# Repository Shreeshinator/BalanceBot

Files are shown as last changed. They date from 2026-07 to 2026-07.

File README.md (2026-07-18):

# BalanceBot

BalanceBot is an ESP32-powered self-balancing robot project built for learning and fast iteration.  
It uses a Smartelex 9DOF board (ISM330DHCX IMU), a TB6612FNG motor driver, and a web-based tuning panel so you can adjust control settings from your phone in real time.

## Highlights

- No external IMU libraries required (direct register reads)
- PID balancing control with anti-windup safeguards
- Kalman-based angle estimation from gyro + accelerometer data
- Built-in Wi-Fi access point and browser UI for live tuning
- One-click **Capture Setpoint** for non-perfect IMU mounting
- Safety cutoff when tilt exceeds the configured safe angle

## Hardware

- ESP32 DevKit V1 (30-pin)
- Smartelex 9DOF (ISM330DHCX + MMC5983MA)
- TB6612FNG dual H-bridge motor driver
- 2 × BO geared motors + wheels
- 2-wheel chassis (included: `Chassis 1.stl`)
- Motor battery pack (typically 6–9V)
- ESP32 power source (USB power bank or regulated 5V)

> Important: motor power and ESP32 logic power should be separate, but all grounds must be shared.

## Quick Start

1. Wire the IMU and TB6612FNG to the ESP32 (see `GUIDE.md` for full pin map and diagrams).
2. Open `BalanceBot.ino` in Arduino IDE.
3. Install **ESP32 by Espressif** board support if needed.
4. Select **ESP32 Dev Module** and upload the sketch.
5. Connect to Wi-Fi: **BalanceBot** (password: **12345678**).
6. Open **http://192.168.4.1**.
7. Hold the robot at its balance point, click **Capture Setpoint**, then **Enable Robot**.
8. Tune Kp/Ki/Kd from the web UI.

## Repository Contents

- `BalanceBot.ino` — complete firmware for balancing, motor control, and web UI
- `GUIDE.md` — full beginner guide (wiring, tuning, troubleshooting)
- `Chassis 1.stl` — chassis model file

## Tuning Notes

- Start with low values and increase gradually.
- Tune **Kp** first, then **Kd**, then **Ki**.
- If motors twitch but do not move, increase `MIN_MOTOR_PWM`.
- If direction is reversed, adjust `MOTOR_LEFT_DIR` / `MOTOR_RIGHT_DIR`.

## License

No license file is currently defined in this repository. Add one if you plan to share or distribute this project publicly.

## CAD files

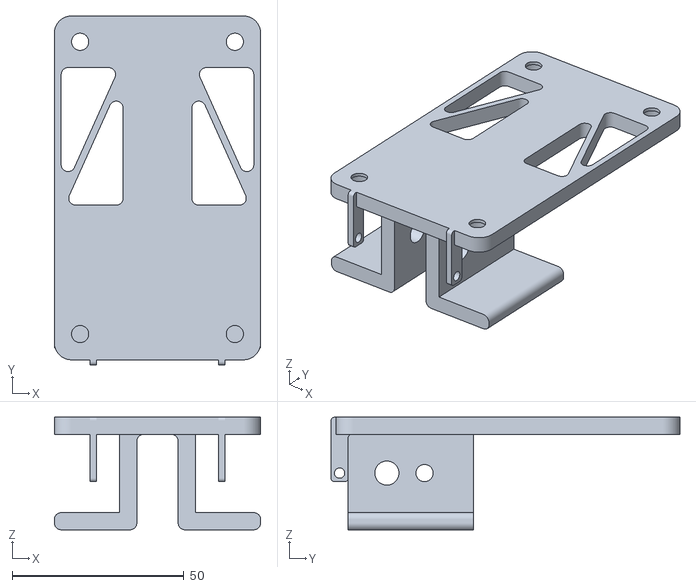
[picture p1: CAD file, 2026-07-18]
Chassis 1.stl
60.0 x 101.5 x 32.8

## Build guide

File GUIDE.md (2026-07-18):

# Self-Balancing Robot — No-Nonsense Beginner's Guide

## What You're Building

A two-wheeled robot that balances on its own like a Segway. An IMU measures how far the robot is tilting; a PID controller decides how fast to spin the motors to catch it. The ESP32 also hosts a WiFi hotspot so you can tune PID values from your phone live.

---

## Parts Checklist

| Part | Qty | Notes |
|---|---|---|
| ESP32 DevKit V1 | 1 | 30-pin variant |
| Smartelex 9DOF (ISM330DHCX + MMC5983MA) | 1 | Only the IMU chip is used for balancing |
| TB6612FNG motor driver | 1 | Dual H-bridge |
| Yellow BO gear motors | 2 | With wheels |
| Robot chassis | 1 | Two-wheeled, top-heavy = more stable |
| LiPo 7.4V or 4×AA 6V pack | 1 | Motor supply |
| USB powerbank OR 5V regulator | 1 | ESP32 supply |
| Jumper wires | many | |
| Breadboard | 1 | Optional but helpful |

**Power rule**: ESP32 and TB6612FNG logic (VCC) run on 3.3V–5V. Motors run on their own supply (VM on TB6612FNG). Always share a common GND.

---

## Wiring

### ISM330DHCX → ESP32

```
IMU Board    ESP32 DevKit V1
─────────    ───────────────
VCC      →   3V3
GND      →   GND
SDA      →   GPIO 21
SCL      →   GPIO 22
SDO/ADDR →   (leave unconnected = I2C addr 0x6A)
INT1/INT2→   (not needed)
```

### TB6612FNG → ESP32 + Battery

```
TB6612FNG   ESP32 / Power
─────────   ─────────────────────────
VCC     →   3V3            (logic power)
VM      →   Battery +      (motor power, 4–9V)
GND     →   GND            (common ground!)
STBY    →   GPIO 4         (pull HIGH to enable)
AIN1    →   GPIO 13
AIN2    →   GPIO 14
PWMA    →   GPIO 26        ← Left motor PWM
BIN1    →   GPIO 27
BIN2    →   GPIO 25
PWMB    →   GPIO 32        ← Right motor PWM
AO1/AO2 →  Left motor terminals
BO1/BO2 →  Right motor terminals
```

> ⚠️ **Critical**: Battery GND and ESP32 GND **must be connected together**. If not, the TB6612FNG direction signals won't work.

---

## About the Smartelex 9DOF Board

- **ISM330DHCX**: 3-axis accelerometer + 3-axis gyroscope by ST  
  - Accel range: ±2/4/8/16g  
  - Gyro range: ±125 to ±4000 dps  
  - I2C address: **0x6A** (default, SDO pin low)  
  - Talks I2C at up to 400 kHz — no library needed, the code reads registers directly
- **MMC5983MA**: magnetometer (compass chip) — not used for balancing  

The code uses **no external libraries** for the IMU. It talks directly to the ISM330DHCX over I2C using register addresses. This means no library to install.

---

## How the Balancing Works

```
   IMU reads tilt angle
          ↓
   Complementary filter
   (gyro + accel fusion)
          ↓
   PID controller
   (angle error → motor command)
          ↓
   TB6612FNG drives motors
   (forward if falling forward,
    backward if falling backward)
```

**Complementary filter** fuses two imperfect sensors:
- Gyroscope: accurate over short time, drifts over time
- Accelerometer: gives absolute angle, but noisy when motors vibrate

Formula: `angle = 0.98 × (angle + gyro_rate × dt) + 0.02 × accel_angle`

**PID controller**:
- **P (Proportional)**: the bigger the tilt, the harder the motor pushes — main balancing force
- **I (Integral)**: fixes a robot that always leans slightly one way
- **D (Derivative)**: slows the response down as it approaches balance — stops oscillation

---

## IMU Mounting & The Setpoint Problem

**The problem**: The IMU reads some non-zero angle when the robot is actually at its balance point, because it's mounted at an angle or not perfectly parallel to the wheel axle.

**The solution**: Don't assume setpoint = 0°. Use the web interface to set it.

### Finding the right setpoint:
1. Upload the code and open Serial Monitor (115200 baud)
2. Hold the robot at the exact point where it would balance (you can feel the "sweet spot" — lean it and find where gravity is neutral)
3. Note the angle shown on Serial Monitor
4. Open the web UI and click **"Capture Current Angle as Setpoint"**

The robot will now try to maintain **that specific angle** instead of 0°.

### Finding the right IMU axis (`PITCH_AXIS`):
In the code at the top, there's `#define PITCH_AXIS 0`. This controls which accelerometer axes are used to calculate tilt.

- Tilt the robot forward. The angle should **increase**.
- Tilt the robot backward. The angle should **decrease**.
- If it's reversed: flip `MOTOR_LEFT_DIR` and `MOTOR_RIGHT_DIR` (easier than changing axis)
- If angle doesn't change at all: try `PITCH_AXIS 1`, recompile, reupload

---

## Arduino IDE Setup

1. **Install ESP32 board support** (if not already):
   - File → Preferences → Additional Board URLs → add:  
     `https://raw.githubusercontent.com/espressif/arduino-esp32/gh-pages/package_esp32_index.json`
   - Tools → Board → Boards Manager → search "esp32" → install "esp32 by Espressif"

2. **No additional libraries needed** — the code uses only built-in ESP32 libraries (Wire, WiFi, WebServer)

3. **Board settings**:
   - Board: `ESP32 Dev Module`
   - Port: your COM/tty port
   - Upload Speed: 921600
   - Flash Frequency: 80MHz
   - Partition Scheme: Default

4. **Upload**: Press and hold the BOOT button on ESP32, click Upload, release BOOT when "Connecting..." appears (some boards do this automatically)

---

## First Run Procedure

```
Step 1: Upload code with Serial Monitor open (115200 baud)
Step 2: You'll see:
        ISM330DHCX WHO_AM_I = 0x6B ✓ OK
        Calibrating gyro — keep robot PERFECTLY STILL for 2 sec...
        Gyro offset: -0.0523 dps
        Initial angle: 12.34°
        WiFi AP "BalanceBot" started. Open: http://192.168.4.1
Step 3: Connect phone/laptop to WiFi: "BalanceBot" (password: 12345678)
Step 4: Open browser → http://192.168.4.1
Step 5: DO NOT enable yet. Hold robot upright, click "Capture Setpoint"
Step 6: Now click "Enable Robot"
Step 7: Robot will try to balance — it will fall many times while tuning PID
```

---

## PID Tuning Guide

Start with all zeros and work up:

### Step 1 — Proportional only
```
Kp = 20, Ki = 0, Kd = 0
```
The robot should react to tilting but oscillate. If it doesn't react at all, increase Kp. If it falls immediately and motors spin max, reduce Kp. Target: robot tries to correct but oscillates quickly.

### Step 2 — Add Derivative
```
Kp = 20, Ki = 0, Kd = 0.5 → increase until oscillation damps
```
Kd slows the response as it approaches vertical. Too much Kd → robot vibrates rapidly (high frequency). Good Kd → robot approaches balance and stops without wobbling.

### Step 3 — Add Integral
```
Ki = 0.2 → increase slowly
```
If the robot stays slightly tilted even when balancing, Ki fixes this. Too much Ki → slow rocking oscillation.

### Typical good starting values for BO motors + lightweight chassis:
```
Kp = 22–35
Ki = 0.3–1.0  
Kd = 0.7–2.0
```

---

## Troubleshooting

| Problem | Fix |
|---|---|
| WHO_AM_I = 0x00 or wrong | Check SDA/SCL wiring. Try I2C address 0x6B (SDO high) |
| Motors don't spin | Check STBY is GPIO 4 and HIGH. Check VM has motor power. Check GND is common |
| Motors spin wrong direction | Flip `MOTOR_LEFT_DIR` or `MOTOR_RIGHT_DIR` to -1 |
| Robot immediately falls | Setpoint is wrong — recapture it. Or Kp is too low |
| Robot oscillates rapidly | Kd too low — increase it. Or Kp too high — reduce |
| Robot slowly rocks back/forth | Ki too high — reduce. Or setpoint slightly off |
| IMU not detected | Verify 3.3V on IMU VCC pin. Try slower I2C: change `Wire.setClock(400000)` to `Wire.setClock(100000)` |
| WiFi not appearing | Normal. Reboot ESP32 and wait 5 seconds |
| Motors twitch but robot doesn't move | Increase `MIN_MOTOR_PWM` from 40 to 60 or 70 |
| LEDC compile error | You're on ESP32 Core 3.x. Replace `ledcSetup+ledcAttachPin` with `ledcAttach(pin, freq, bits)` and `ledcWrite(pin, duty)` |

---

## Getting Maximum Stability

1. **Mount the IMU rigidly** — vibration = noisy accel = bad angle estimate. Hot glue or bolt it down. Don't let it flex.

2. **Centre of mass high** — counter-intuitively, a higher CoM (battery on top) makes balancing **easier** because it falls more slowly. Low CoM = fast tipping = hard to catch.

3. **Wheels with grip** — slipping wheels mean the robot can't catch itself.

4. **Adequate motor power** — BO motors with 6V+ battery respond faster. At 3.7V they're sluggish.

5. **Keep the loop fast** — `handleClient()` is the slowest part. Typical loop rate is 150–250 Hz which is fine.

6. **Anti-windup** — already in the code. Don't remove the `pidIntegral` clamp.

7. **Increase compAlpha** — try 0.985 or 0.99 if you have motor vibration noise. Higher = more gyro trust = smoother but slightly more drift.

---

## Files

- `BalanceBot.ino` — the complete code, upload this directly in Arduino IDE

---

*No extra libraries needed. WiFi is hotspot mode (no router required). Tune from any browser.*

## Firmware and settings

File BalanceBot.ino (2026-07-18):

/*
  SELF-BALANCING ROBOT
  ESP32 DevKit V1 + Smartelex 9DOF (ISM330DHCX) + TB6612FNG
  
  Features:
    - No-library IMU (direct register access, no install needed)
    - Kalman filter (accel + gyro fusion)
    - PID controller with anti-windup
    - WiFi Access Point + live web tuner at 192.168.4.1
    - "Capture Setpoint" button for angled IMU mounting
    - Safety cutoff if robot falls too far

  TB6612FNG  →  ESP32 / Power
    VCC  →  3V3 (logic supply)
    VM   →  Battery+ (4–9V motor supply)
    GND  →  GND (shared with ESP32 and battery -)
    STBY →  GPIO 4
    AIN1 →  GPIO 13
    AIN2 →  GPIO 14
    PWMA →  GPIO 26   ← Left Motor speed
    BIN1 →  GPIO 27
    BIN2 →  GPIO 25
    PWMB →  GPIO 32   ← Right Motor speed
  ─────────────────────────────────────────────────
  NOTE: Use a common GND between ESP32 and battery.
  Power ESP32 from its VIN (5V from regulator/USB powerbank)
  or USB. Don't share motor power with ESP32 3.3V rail.
*/

#include <Wire.h>
#include <WiFi.h>
#include <WebServer.h>
#include <math.h>

//  SECTION 1: USER CONFIG — Edit these first!

// --- IMU Axis Selection ---
// With IMU mounted flat (sensor side up):
//   PITCH_AXIS = 0  → uses atan2(ax, az)  [most common]
// With IMU rotated 90° (mounted on side panel, landscape):
//   PITCH_AXIS = 1  → uses atan2(ay, az)
// With IMU tilted (another orientation):
//   PITCH_AXIS = 2  → uses atan2(ax, ay)
//
// HOW TO FIND THE RIGHT ONE:
//   Open Serial Monitor at 115200. Tilt robot forward/back.
//   The angle should increase when leaning forward and
//   decrease when leaning back. Try each until it works.
#define PITCH_AXIS   0     // 0, 1, or 2 — see above

// Matching gyro axis for pitch rate (usually same as PITCH_AXIS)
//   0 = gx,  1 = gy,  2 = gz
#define GYRO_AXIS    1     // 0, 1, or 2

// --- Motor Direction ---
// If a motor spins the wrong way, flip its sign here.
// Correct behavior: positive output → robot moves forward.
#define MOTOR_LEFT_DIR   1    //  1 or -1
#define MOTOR_RIGHT_DIR -1    //  1 or -1

// --- WiFi ---
#define WIFI_SSID  "BalanceBot"
#define WIFI_PASS  "12345678"

//  SECTION 2: PIN DEFINITIONS

// I2C (ISM330DHCX)
#define PIN_SDA   21
#define PIN_SCL   22

// TB6612FNG Motor Driver
#define PIN_STBY  4     // Standby — HIGH to enable driver

#define PIN_AIN1  13   // Motor A (Left) direction
#define PIN_AIN2  14
#define PIN_PWMA  26    // Motor A speed (PWM)

#define PIN_BIN1  27    // Motor B (Right) direction
#define PIN_BIN2  25
#define PIN_PWMB  32    // Motor B speed (PWM)

// LEDC (ESP32 hardware PWM)
#define LEDC_CHAN_A   0
#define LEDC_CHAN_B   1
#define LEDC_FREQ     10000   // 10 kHz — inaudible, smooth
#define LEDC_BITS     8       // 8-bit resolution (0–255)

//  SECTION 3: ISM330DHCX REGISTER DEFINITIONS

// I2C address (SDO pin unconnected = pulled low = 0x6A)
// If your board has SDO connected to 3.3V, use 0x6B
#define ISM330_ADDR   0x6B

#define REG_WHO_AM_I  0x0F   // Should return 0x6B
#define REG_CTRL1_XL  0x10   // Accelerometer config
#define REG_CTRL2_G   0x11   // Gyroscope config
#define REG_CTRL3_C   0x12   // General config
#define REG_OUTX_L_G  0x22   // Gyro output start (6 bytes)
#define REG_OUTX_L_A  0x28   // Accel output start (6 bytes)

// Sensitivity for our chosen full-scale ranges:
//   Gyro  ±500 dps  → 17.5 mdps/LSB
//   Accel ±2 g      → 0.061 mg/LSB
#define GYRO_SCALE    0.0175f      // dps per raw LSB
#define ACCEL_SCALE   0.000061f    // g   per raw LSB

//  SECTION 4: PID & FILTER DEFAULTS
//
// These are starting points. Tune via the web interface.
//
// Typical tuning procedure:
//   1. Set Ki=0, Kd=0. Increase Kp until robot oscillates.
//   2. Halve Kp. Increase Kd until oscillations damp.
//   3. Increase Ki slowly to remove residual lean.
//   4. Fine-tune setpoint with "Capture" button in web UI.

float Kp = 25.0f;
float Ki = 0.4f;
float Kd = 0.9f;

// Balance angle — NOT 0° if your IMU is mounted at an angle!
// Use the web interface "Capture Setpoint" button to set this
// while holding the robot at its physical balance point.
float setpoint = 0.0f;

// Safety: cut motors if robot leans more than this from setpoint
float maxSafeAngle = 70.0f;

// Complementary filter weight (0 = trust only accel, 1 = trust only gyro)
// 0.98 is the sweet spot for balance bots
float compAlpha = 0.98f;

// Minimum PWM to actually move BO motors (they stall below ~40)
#define MIN_MOTOR_PWM  50

// =========================================================
//  SECTION 5: GLOBAL STATE
// =========================================================

float currentAngle  = 0.0f;
float currentOutput = 0.0f;
float gyroOffset    = 0.0f;   // Calibrated gyro zero

float pidIntegral   = 0.0f;
float pidLastError  = 0.0f;

bool robotEnabled   = false;  // Start disabled — enable from web UI
unsigned long lastLoopUs = 0;

float loopHz = 0.0f;

float kalAngle = 0, kalBias = 0;
float kalP[2][2] = {{0,0},{0,0}};
// Tune these if needed:
const float kalQ_angle = 0.001f;  // Process noise: angle
const float kalQ_bias  = 0.003f;  // Process noise: bias drift
const float kalR_meas  = 0.03f; 

WebServer webServer(80);

// NEW --> dual core rtos split for pid and webserver
TaskHandle_t pidTaskHandle;
//protos
void imuReadAll(float&, float&, float&, float&, float&, float&);
float kalmanUpdate(float measuredAngle, float gyroRate, float dt);
void motorsOff();
void setMotors(float);
bool imuInit();
void calibrateGyro();
void setupWebServer();

void pidTask(void* pvParams) {
  lastLoopUs = micros();
  for (;;) {
    unsigned long nowUs = micros();
    float dt = (nowUs - lastLoopUs) / 1000000.0f;
    lastLoopUs = nowUs;
    dt = constrain(dt, 0.001f, 0.02f);

    float ax, ay, az, gx, gy, gz;
    imuReadAll(ax, ay, az, gx, gy, gz);

    float gyroRate;
    if      (GYRO_AXIS == 0) gyroRate = gx - gyroOffset;
    else if (GYRO_AXIS == 1) gyroRate = gy - gyroOffset;
    else                     gyroRate = gz - gyroOffset;

    float accelAngle;
    if      (PITCH_AXIS == 0) accelAngle = atan2f(ax, az) * 180.0f / M_PI;
    else if (PITCH_AXIS == 1) accelAngle = atan2f(ay, az) * 180.0f / M_PI;
    else                      accelAngle = atan2f(ax, ay) * 180.0f / M_PI;

  static float accelAngleFiltered = 0;
  accelAngleFiltered = 0.7f * accelAngleFiltered + 0.3f * accelAngle;
  // Then use accelAngleFiltered instead of accelAngle in the filter
    currentAngle = kalmanUpdate(accelAngleFiltered, gyroRate, dt);

    loopHz = 0.95f * loopHz + 0.05f * (1.0f / dt);

    float error = currentAngle - setpoint;
    if (!robotEnabled || fabsf(error) > maxSafeAngle) {
      motorsOff();
      pidIntegral = 0.0f;
      currentOutput = 0.0f;
      vTaskDelay(1);
      continue;
    }

    float Pout = Kp * error;
    pidIntegral += error * dt;
    float integralLimit = (Ki > 0.001f) ? (200.0f / Ki) : 5000.0f;
    pidIntegral = constrain(pidIntegral, -integralLimit, integralLimit);
    float Iout = Ki * pidIntegral;
    // D term: use raw gyro directly — WAY cleaner than differencing angle
    float Dout = -Kd * gyroRate;   // <-- see change #2 below

    currentOutput = Pout + Iout + Dout;
    setMotors(currentOutput);

    // Target ~500Hz — adjust this number
    vTaskDelay(pdMS_TO_TICKS(2));
  static unsigned long dbg = 0;
  if (millis() - dbg > 1000) {
    Serial.printf("enabled=%d  angle=%.2f  error=%.2f  output=%.1f\n",
      robotEnabled, currentAngle, currentAngle - setpoint, currentOutput);
    dbg = millis();
  }
  }
}

// =========================================================
//  SECTION 6: IMU FUNCTIONS
// =========================================================

void imuWrite(uint8_t reg, uint8_t val) {
  Wire.beginTransmission(ISM330_ADDR);
  Wire.write(reg);
  Wire.write(val);
  Wire.endTransmission();
}

uint8_t imuRead(uint8_t reg) {
  Wire.beginTransmission(ISM330_ADDR);
  Wire.write(reg);
  Wire.endTransmission(false);
  Wire.requestFrom(ISM330_ADDR, (uint8_t)1);
  return Wire.available() ? Wire.read() : 0;
}

// Read all 6 axes in one I2C burst (efficient, no missed frames)
void imuReadAll(float &ax, float &ay, float &az,
                float &gx, float &gy, float &gz) {
  Wire.beginTransmission(ISM330_ADDR);
  Wire.write(REG_OUTX_L_G);
  Wire.endTransmission(false);
  Wire.requestFrom(ISM330_ADDR, (uint8_t)12);

  // Gyro first (3 axes × 2 bytes), then Accel (3 axes × 2 bytes)
  int16_t rawGX = (int16_t)(Wire.read() | (Wire.read() << 8));
  int16_t rawGY = (int16_t)(Wire.read() | (Wire.read() << 8));
  int16_t rawGZ = (int16_t)(Wire.read() | (Wire.read() << 8));
  int16_t rawAX = (int16_t)(Wire.read() | (Wire.read() << 8));
  int16_t rawAY = (int16_t)(Wire.read() | (Wire.read() << 8));
  int16_t rawAZ = (int16_t)(Wire.read() | (Wire.read() << 8));

  gx = rawGX * GYRO_SCALE;
  gy = rawGY * GYRO_SCALE;
  gz = rawGZ * GYRO_SCALE;
  ax = rawAX * ACCEL_SCALE;
  ay = rawAY * ACCEL_SCALE;
  az = rawAZ * ACCEL_SCALE;
}

bool imuInit() {
  Wire.begin(PIN_SDA, PIN_SCL);
  Wire.setClock(400000);   // 400 kHz fast mode
  delay(20);

  uint8_t id = imuRead(REG_WHO_AM_I);
  Serial.printf("ISM330DHCX WHO_AM_I = 0x%02X", id);
  if (id == 0x6B) {
    Serial.println(" ✓ OK");
  } else {
    Serial.println(" ✗ FAIL — check wiring & I2C address!");
    return false;
  }

  // CTRL1_XL: ODR=208 Hz (0101xxxx), FS=±2g (xx00xxxx)
  // Byte: 0101 0000 = 0x50
  imuWrite(REG_CTRL1_XL, 0x50);

  // CTRL2_G: ODR=208 Hz (0101xxxx), FS=±500 dps (xxx0 10xx)
  // Byte: 0101 0100 = 0x54
  imuWrite(REG_CTRL2_G, 0x54);

  // CTRL3_C: BDU=1 (block data update, bit6), IF_INC=1 (auto addr inc, bit2)
  // Byte: 0100 0100 = 0x44
  imuWrite(REG_CTRL3_C, 0x44);

  delay(100);   // Let ODR settle
  return true;
}

void calibrateGyro() {
  Serial.println("Calibrating gyro — keep robot PERFECTLY STILL for 2 sec...");
  const int N = 400;
  float sum = 0;
  for (int i = 0; i < N; i++) {
    float ax, ay, az, gx, gy, gz;
    imuReadAll(ax, ay, az, gx, gy, gz);
    float g = (GYRO_AXIS == 0) ? gx : (GYRO_AXIS == 1) ? gy : gz;
    sum += g;
    delay(5);
  }
  gyroOffset = sum / N;
  Serial.printf("Gyro offset: %.4f dps\n", gyroOffset);

  // Seed angle from accelerometer so filter starts correct
  float ax, ay, az, gx, gy, gz;
  imuReadAll(ax, ay, az, gx, gy, gz);
  if      (PITCH_AXIS == 0) currentAngle = atan2f(ax, az) * 180.0f / M_PI;
  else if (PITCH_AXIS == 1) currentAngle = atan2f(ay, az) * 180.0f / M_PI;
  else                      currentAngle = atan2f(ax, ay) * 180.0f / M_PI;
  Serial.printf("Initial angle: %.2f°\n", currentAngle);
  kalAngle = currentAngle;
}

// =========================================================
//  SECTION 7: MOTOR CONTROL
// =========================================================

void motorsInit() {
  pinMode(PIN_AIN1, OUTPUT);  pinMode(PIN_AIN2, OUTPUT);
  pinMode(PIN_BIN1, OUTPUT);  pinMode(PIN_BIN2, OUTPUT);
  pinMode(PIN_STBY, OUTPUT);
  digitalWrite(PIN_STBY, HIGH);  // Enable driver

  // ESP32 Arduino Core 2.x LEDC API
  // (If you're on Core 3.x, replace with ledcAttach(pin, freq, bits))
  ledcAttach(PIN_PWMA, LEDC_FREQ, LEDC_BITS);
  ledcAttach(PIN_PWMB, LEDC_FREQ, LEDC_BITS);
}

// Drive one H-bridge channel. speed: -255 to +255
void driveChannel(uint8_t in1, uint8_t in2, uint8_t pwmPin, int speed) {
  speed = constrain(speed, -255, 255);
  if (speed > 0) {
    digitalWrite(in1, HIGH); digitalWrite(in2, LOW);
    ledcWrite(pwmPin, speed);
  } else if (speed < 0) {
    digitalWrite(in1, LOW);  digitalWrite(in2, HIGH);
    ledcWrite(pwmPin, -speed);
  } else {
    // Fast decay (coast): both inputs LOW
    digitalWrite(in1, LOW);  digitalWrite(in2, LOW);
    ledcWrite(pwmPin, 0);
  }
}

// Apply PID output to both motors.
// Positive output = both motors drive "forward" (catching a forward lean).
void setMotors(float rawOutput) {
  int out = (int)constrain(rawOutput, -255.0f, 255.0f);

  // Dead zone: too small to do anything → zero
  if (abs(out) < 12) {
    out = 0;
  }
// Stiction zone: too small to move but non-trivial → snap to minimum
  else if (abs(out) < MIN_MOTOR_PWM) {
    out = (out > 0) ? MIN_MOTOR_PWM : -MIN_MOTOR_PWM;
  }

  driveChannel(PIN_AIN1, PIN_AIN2, PIN_PWMA, MOTOR_LEFT_DIR  * out);
  driveChannel(PIN_BIN1, PIN_BIN2, PIN_PWMB, MOTOR_RIGHT_DIR * out);
}

void motorsOff() {
  driveChannel(PIN_AIN1, PIN_AIN2, PIN_PWMA, 0);
  driveChannel(PIN_BIN1, PIN_BIN2, PIN_PWMB, 0);
}

// =========================================================
//  SECTION 8: WEB INTERFACE HTML
// =========================================================

// Stored in flash (PROGMEM) to save RAM
const char INDEX_HTML[] PROGMEM = R"rawhtml(
<!DOCTYPE html><html lang="en">
<head>
<meta charset="UTF-8">
<meta name="viewport" content="width=device-width,initial-scale=1">
<title>BalanceBot Tuner</title>
<style>
*{box-sizing:border-box;margin:0;padding:0}
body{background:#0d1117;color:#c9d1d9;font-family:system-ui,sans-serif;padding:14px;max-width:480px;margin:auto}
h1{font-size:1.3em;color:#58a6ff;margin-bottom:14px}
.card{background:#161b22;border:1px solid #30363d;border-radius:10px;padding:14px;margin-bottom:12px}
.row{display:flex;gap:12px}
.cell{flex:1;text-align:center}
.big{font-size:2em;font-weight:700;line-height:1.1}
.green{color:#3fb950}.red{color:#f85149}.blue{color:#58a6ff}.yellow{color:#d29922}
.sub{font-size:.75em;color:#8b949e;margin-top:2px}
.bar-bg{height:10px;background:#21262d;border-radius:5px;overflow:hidden;margin:10px 0}
.bar{height:100%;background:#58a6ff;border-radius:5px;transition:width .08s}
label{display:block;font-size:.8em;color:#8b949e;margin:10px 0 3px}
input[type=number]{width:100%;background:#21262d;color:#c9d1d9;border:1px solid #30363d;border-radius:6px;padding:7px 10px;font-size:.95em}
input[type=number]:focus{border-color:#58a6ff;outline:none}
.btn{width:100%;border:none;border-radius:7px;padding:10px;font-size:.95em;cursor:pointer;margin-top:6px;font-weight:600}
.btn-blue{background:#1f6feb;color:#fff}
.btn-green{background:#238636;color:#fff}
.btn-red{background:#da3633;color:#fff}
.btn-gray{background:#21262d;color:#c9d1d9;border:1px solid #30363d}
.tip{font-size:.78em;color:#8b949e;line-height:1.5}
.tip b{color:#d29922}
.status{font-size:.8em;margin-top:8px}
.dot{display:inline-block;width:8px;height:8px;border-radius:50%;margin-right:5px}
</style>
</head>
<body>
<h1>⚖️ BalanceBot Tuner</h1>

<div class="card">
  <div class="row">
    <div class="cell">
      <div class="sub">Tilt Angle</div>
      <div class="big" id="ang" style="color:#58a6ff">--</div>
      <div class="sub">degrees</div>
    </div>
    <div class="cell">
      <div class="sub">Motor Drive</div>
      <div class="big" id="out" style="color:#3fb950">--</div>
      <div class="sub">/ ±255</div>
    </div>
    <div class="cell">
      <div class="sub">Loop Rate</div>
      <div class="big" id="hz" style="color:#d29922">--</div>
      <div class="sub">Hz</div>
    </div>
  </div>
  <div class="bar-bg"><div class="bar" id="angbar" style="width:50%"></div></div>
  <div class="status" id="statusline"><span class="dot" style="background:#555" id="dot"></span>Connecting...</div>
</div>

<div class="card">
  <b style="color:#c9d1d9">PID Parameters</b>
  <label>Kp — Proportional (main restoring force, 15-40 typical)</label>
  <input type="number" id="kp" step="0.5" min="0" max="200">
  <label>Ki — Integral (removes steady lean, 0-2 typical)</label>
  <input type="number" id="ki" step="0.05" min="0" max="20">
  <label>Kd — Derivative (damps oscillation, 0.5-3 typical)</label>
  <input type="number" id="kd" step="0.05" min="0" max="20">
  <label>Setpoint (°) — angle where robot balances</label>
  <input type="number" id="sp" step="0.1">
  <label>Max Safe Angle (°) — motors cut if exceeded</label>
  <input type="number" id="ma" step="1" min="5" max="90">
  <button class="btn btn-blue" onclick="applyPID()">✓ Apply Parameters</button>
  <button class="btn btn-gray" onclick="captureSetpoint()" style="margin-top:5px">
    📐 Capture Current Angle as Setpoint
  </button>
</div>

<div class="card row" style="gap:8px">
  <button class="btn btn-green" onclick="setEn(1)">▶ Enable Robot</button>
  <button class="btn btn-red" onclick="setEn(0)">■ Disable</button>
</div>

<div class="card">
  <b style="color:#d29922">Tuning Guide</b>
  <p class="tip" style="margin-top:8px">
    <b>Step 1</b> — Set Ki=0, Kd=0. Raise Kp until robot tries to balance but oscillates.<br>
    <b>Step 2</b> — Halve Kp. Raise Kd to damp oscillations.<br>
    <b>Step 3</b> — Raise Ki slowly (0.1 at a time) to fix residual lean.<br>
    <b>Step 4</b> — If motors twitch but robot doesn't move, raise MIN_MOTOR_PWM in code.<br>
    <b>Setpoint</b> — Hold robot at real balance point, click Capture. Re-enable.
  </p>
</div>

<script>
let liveAngle=0, lastTime=Date.now(), loopCnt=0;

async function poll(){
  try{
    const d=await(await fetch('/data')).json();
    liveAngle=d.angle;
    document.getElementById('ang').textContent=d.angle.toFixed(1);
    document.getElementById('out').textContent=(d.output>=0?'+':'')+Math.round(d.output);
    document.getElementById('hz').textContent=Math.round(d.hz);
    // Angle bar: ±30° mapped to 0-100%
    const pct=Math.min(Math.max(50+d.angle*100/60,2),98);
    document.getElementById('angbar').style.width=pct+'%';
    const col=d.enabled?'#3fb950':'#f85149';
    document.getElementById('dot').style.background=col;
    document.getElementById('statusline').innerHTML=
      '<span class="dot" style="background:'+col+'" id="dot"></span>'+
      (d.enabled?'🟢 Robot ENABLED':'🔴 Robot DISABLED')+
      ' | Setpoint: '+d.sp.toFixed(1)+'°';
    // Sync inputs on first load
    if(!document.getElementById('kp').dataset.set){
      ['kp','ki','kd','sp','ma'].forEach(k=>{
        document.getElementById(k).value=d[k];
      });
      document.getElementById('kp').dataset.set='1';
    }
  }catch(e){}
}

function applyPID(){
  const p=new URLSearchParams({
    kp:document.getElementById('kp').value,
    ki:document.getElementById('ki').value,
    kd:document.getElementById('kd').value,
    sp:document.getElementById('sp').value,
    ma:document.getElementById('ma').value
  });
  fetch('/set?'+p).then(poll);
}

function captureSetpoint(){
  document.getElementById('sp').value=liveAngle.toFixed(2);
  fetch('/set?sp='+liveAngle.toFixed(3))
    .then(()=>alert('Setpoint locked to '+liveAngle.toFixed(2)+'°'));
}

function setEn(v){fetch('/enable?v='+v).then(poll);}

setInterval(poll,120);
poll();
</script>
</body></html>
)rawhtml";

// =========================================================
//  SECTION 9: WEB SERVER SETUP
// =========================================================

   // Measured loop rate for web display

void setupWebServer() {
  webServer.on("/", []() {
    webServer.send_P(200, "text/html", INDEX_HTML);
  });

  // Live telemetry JSON endpoint
  webServer.on("/data", []() {
    String j = "{";
    j += "\"angle\":"  + String(currentAngle,  3) + ",";
    j += "\"output\":" + String(currentOutput, 1) + ",";
    j += "\"hz\":"     + String(loopHz,         1) + ",";
    j += "\"enabled\":" + String(robotEnabled ? "true" : "false") + ",";
    j += "\"kp\":"     + String(Kp,         2) + ",";
    j += "\"ki\":"     + String(Ki,         4) + ",";
    j += "\"kd\":"     + String(Kd,         4) + ",";
    j += "\"sp\":"     + String(setpoint,   3) + ",";
    j += "\"ma\":"     + String(maxSafeAngle, 1);
    j += "}";
    webServer.send(200, "application/json", j);
  });

  // Apply PID params
  webServer.on("/set", []() {
    if (webServer.hasArg("kp")) Kp           = webServer.arg("kp").toFloat();
    if (webServer.hasArg("ki")) Ki           = webServer.arg("ki").toFloat();
    if (webServer.hasArg("kd")) Kd           = webServer.arg("kd").toFloat();
    if (webServer.hasArg("sp")) setpoint     = webServer.arg("sp").toFloat();
    if (webServer.hasArg("ma")) maxSafeAngle = webServer.arg("ma").toFloat();
    pidIntegral = 0.0f;  // Reset integral whenever params change
    webServer.send(200, "text/plain", "OK");
  });

  // Enable / Disable
  webServer.on("/enable", []() {
    if (webServer.hasArg("v")) {
      robotEnabled = (webServer.arg("v").toInt() == 1);
      if (!robotEnabled) { motorsOff(); pidIntegral = 0.0f; }
    }
    webServer.send(200, "text/plain", "OK");
  });

  webServer.begin();
}

// Optionl testing kalman filter
// ---- Kalman Filter State ----
// float kalAngle = 0, kalBias = 0;
// float kalP[2][2] = {{0,0},{0,0}};
// // Tune these if needed:
// const float kalQ_angle = 0.001f;  // Process noise: angle
// const float kalQ_bias  = 0.003f;  // Process noise: bias drift
// const float kalR_meas  = 0.03f;   // Measurement noise (higher = smoother, laggier)

float kalmanUpdate(float measuredAngle, float gyroRate, float dt) {
  // Predict step
  kalAngle += dt * (gyroRate - kalBias);
  kalP[0][0] += dt * (dt*kalP[1][1] - kalP[0][1] - kalP[1][0] + kalQ_angle);
  kalP[0][1] -= dt * kalP[1][1];
  kalP[1][0] -= dt * kalP[1][1];
  kalP[1][1] += kalQ_bias * dt;

  // Update step
  float S  = kalP[0][0] + kalR_meas;
  float K0 = kalP[0][0] / S;
  float K1 = kalP[1][0] / S;
  float innov = measuredAngle - kalAngle;
  kalAngle += K0 * innov;
  kalBias  += K1 * innov;
  float P00_temp = kalP[0][0];
  float P01_temp = kalP[0][1];
  kalP[0][0] -= K0 * P00_temp;
  kalP[0][1] -= K0 * P01_temp;
  kalP[1][0] -= K1 * P00_temp;
  kalP[1][1] -= K1 * P01_temp;
  return kalAngle;
}
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
// void loop() { //testing
//     digitalWrite(PIN_STBY, HIGH);

//     digitalWrite(PIN_AIN1, HIGH);
//     digitalWrite(PIN_AIN2, LOW);
//     ledcWrite(PIN_PWMA, 255);

//     digitalWrite(PIN_BIN1, HIGH);
//     digitalWrite(PIN_BIN2, LOW);
//     ledcWrite(PIN_PWMB, 255);

//     delay(1000);
// }
